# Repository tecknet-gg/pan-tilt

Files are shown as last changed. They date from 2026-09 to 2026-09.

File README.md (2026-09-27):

<div align="center">

  <h1>pan-tilt</h1>

  <p>An alt-azimouth mount for patch antennas up to 500mm x 500mm in size.</p>

<p align="center">
  pan-tilt render
</p>

</div>

# Overview

A custom, adjustable alt-azimouth mount that can manipulate a patch antenna of up to 500mm x 500mm in size. The base is built using 4 hollow aluminium rods with an inner diameter or 27mm, and a thickness of 3mm, connected using a PLA connector and M3 bolts to fasten. Powered by either 2 or 3 NEMA 17 steppers (3 if tilt is driven by two steppers), stepped down using GT2 pulleys and timing belts in a 1:4 ratio for more torque. It was intended to track a CanSat during its descent (it can track ascent too given distance between launch site and antenna is great enough). The mount has been constructed, but hasn't been tested under load since we didn't make national finals...

# Assembly 
I do not know why you would assemble this, but in case you do... 

Print out the following files in their specified quantity. I used PLA, but PETG would probably be more ideal.

>[!NOTE]
> The antenna mount was for the antenna we used. You'll have to make your own of course. It will have to mount to a GT2 pulley. I used a clamp joint for the same.

| file | qty |
| --- | --- |
| pan connector.step  | 1 |
| antenna mount.step  | 2 |
| base mount.step | 1 |
| tilt connector.step | 2 |

Insert your 4 aluminium rods of OD 30mm and length 300mm into the pan connector. Fasten with 4 M3x6ish bolts into the sides. Attach the two tilt connectors, one on either side, and attach to the rods using 4 M3x6ish bolts for each connector. This is the adjustable part, and can be moved down the length of the rods to accommodate different sized antennas, and balance the mount. 

Now thread a long M3 bolt down the centre of the pan connector, and thread it through the GT2 100 teeth pulley, and then tighten with bolts. Attach the timing belt, and then the smaller GT2 20 tooth pulley. After that, mount one NEMA 17 motor using M3xsomething bolts, and attach the GT2 20 teeth pulley to the shaft and tighten the grub screw. 

Now for the tilt, first press fit 608-2Z deep groove bearings into both connectors. Mount a NEMA 17 motor onto the tilt connector. Attach a GT2 20 tooth pulley to the shaft of the same. Attach the timing belt. Using another long M3 shaft, thread it through the GT2 100 tooth pulley, with your custom antenna mount before it. Use some spacers to go through the bearing, and then tighten on the other side with a bolt. Repeat on the other side if needed (if you don't you'll have to counterbalance it). 

And with that you should be done!

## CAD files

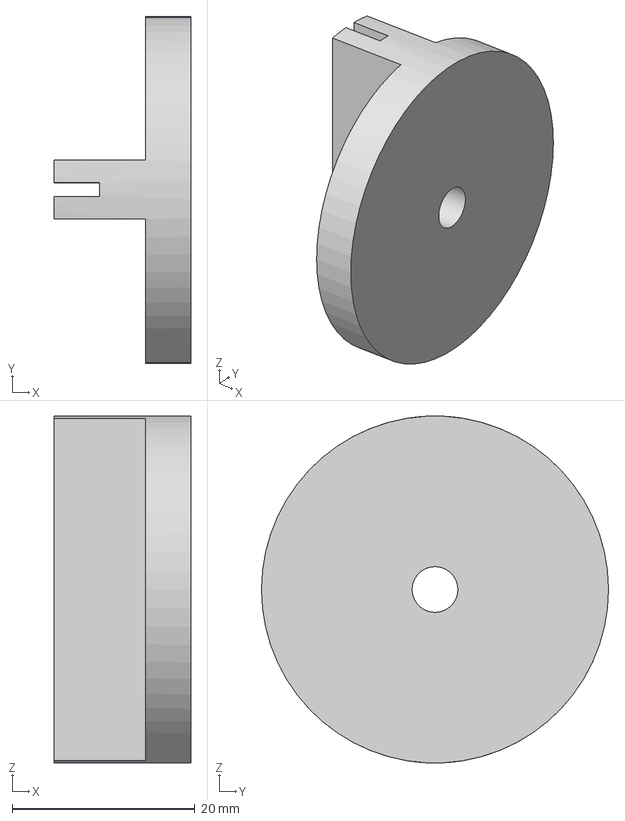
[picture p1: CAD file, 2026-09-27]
hardware/antenna mount.step
15.0 x 38.0 x 38.0 mm

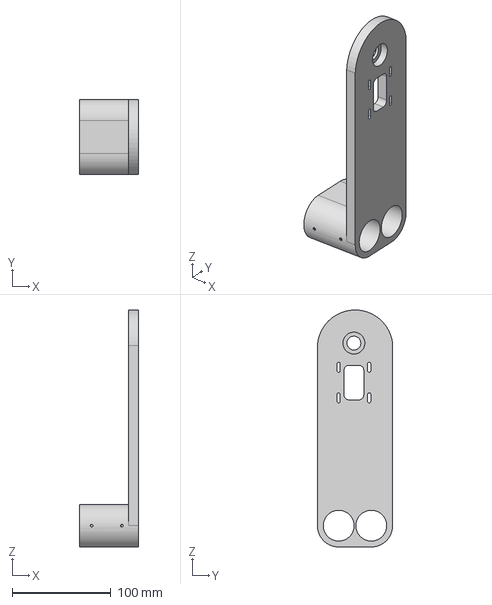
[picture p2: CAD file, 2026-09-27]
hardware/titl connector.step
60.0 x 76.2 x 240.1 mm

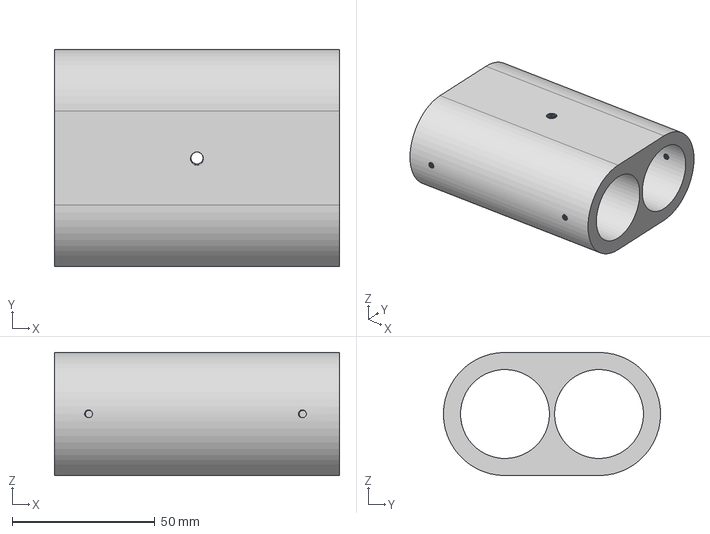
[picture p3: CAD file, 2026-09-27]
hardware/pan connector.step
100.0 x 76.2 x 43.2 mm

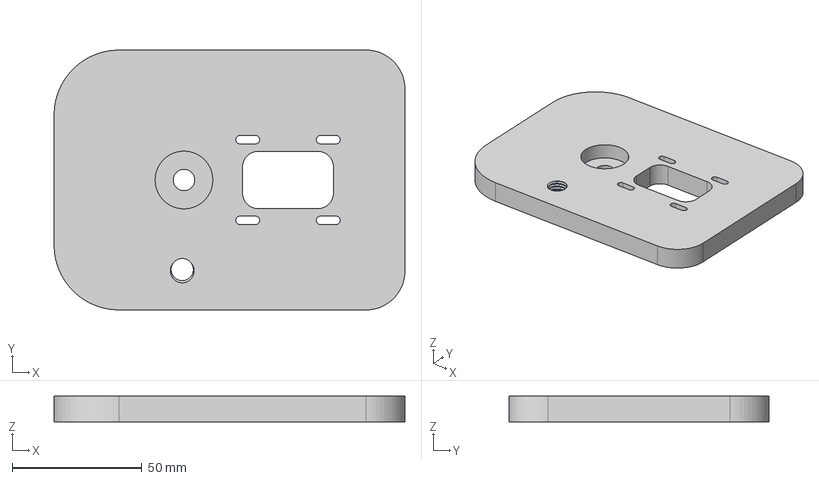
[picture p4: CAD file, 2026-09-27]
hardware/base mount.step
135.0 x 100.0 x 10.0 mm

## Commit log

2026-09-27 Create hardware folder to upload CAD files.
2026-09-27 Add .step files
    [antenna mount.step, base mount.step, pan connector.step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]
